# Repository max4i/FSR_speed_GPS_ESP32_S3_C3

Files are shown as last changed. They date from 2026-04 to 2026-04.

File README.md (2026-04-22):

# FSR Speed Tracker v9.5

## Telemetria dla łodzi wyścigowych FSR

## Spis treści

1. [Opis ogólny](#opis-ogólny)
2. [Wersja ESP32-S3 (pełna)](#wersja-esp32-s3-pełna)
3. [Wersja ESP32-C3 (lekka)](#wersja-esp32-c3-lekka)
4. [Porównanie wersji](#porównanie-wersji)
5. [Budowa i podłączenia](#budowa-i-podłączenia)
6. [Instalacja oprogramowania](#instalacja-oprogramowania)
7. [Konfiguracja](#konfiguracja)
8. [Obsługa systemu](#obsługa-systemu)
9. [Funkcje zaawansowane](#funkcje-zaawansowane)
10. [Rozwiązywanie problemów](#rozwiązywanie-problemów)
11. [Dane techniczne](#dane-techniczne)

---
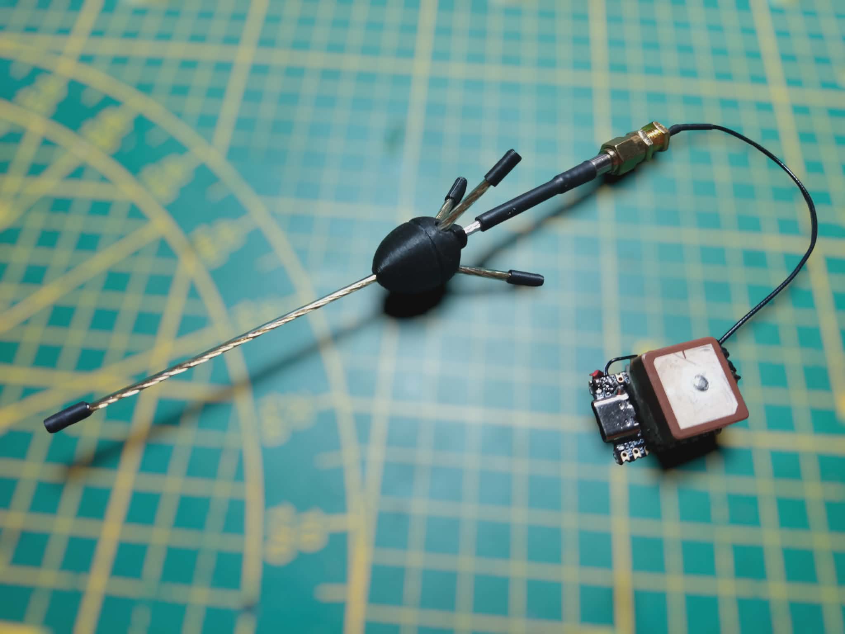
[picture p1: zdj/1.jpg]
[](zdj/1.jpg)
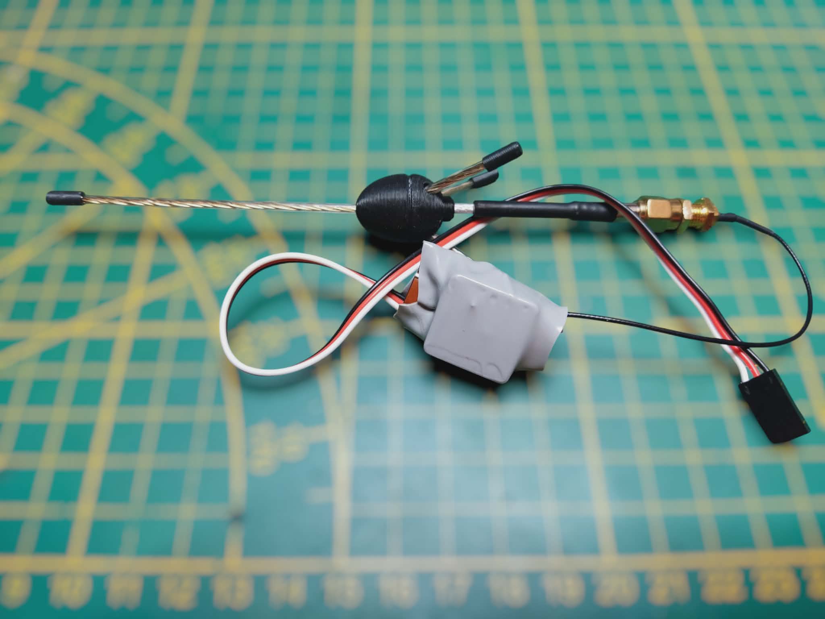
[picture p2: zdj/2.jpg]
[](zdj/2.jpg)
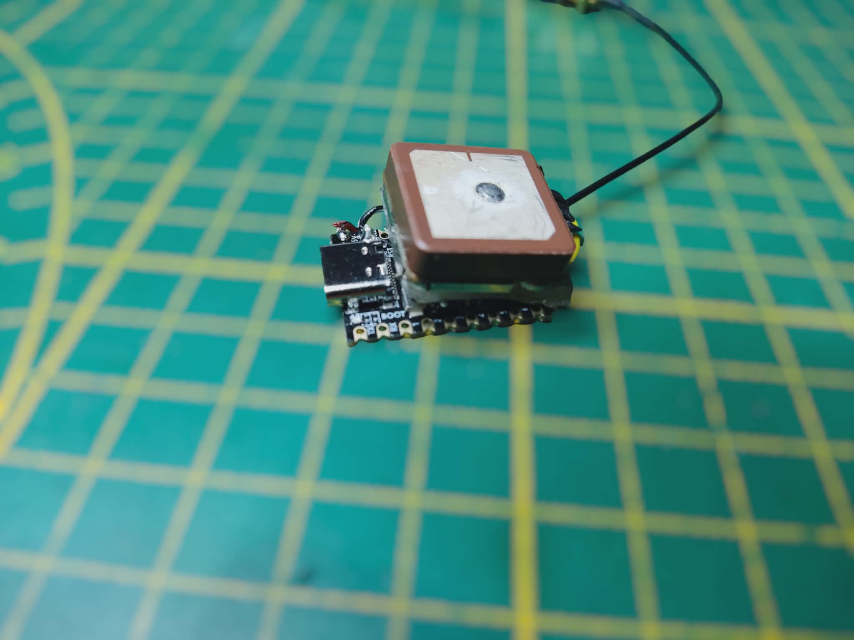
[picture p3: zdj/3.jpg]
[](zdj/3.jpg)

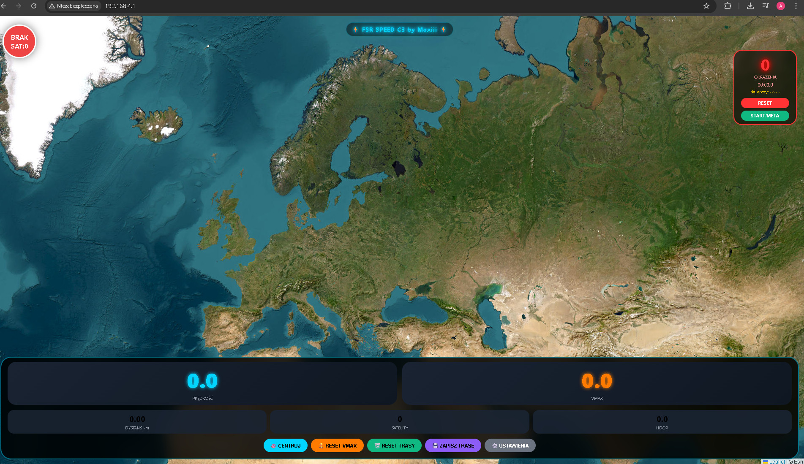
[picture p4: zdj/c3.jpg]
[](zdj/c3.jpg)
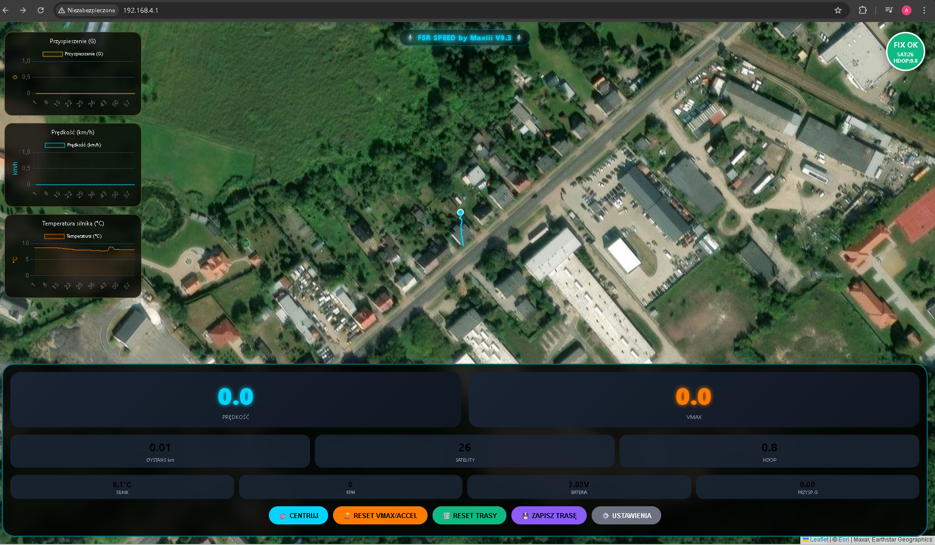
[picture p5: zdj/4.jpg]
[](zdj/4.jpg)

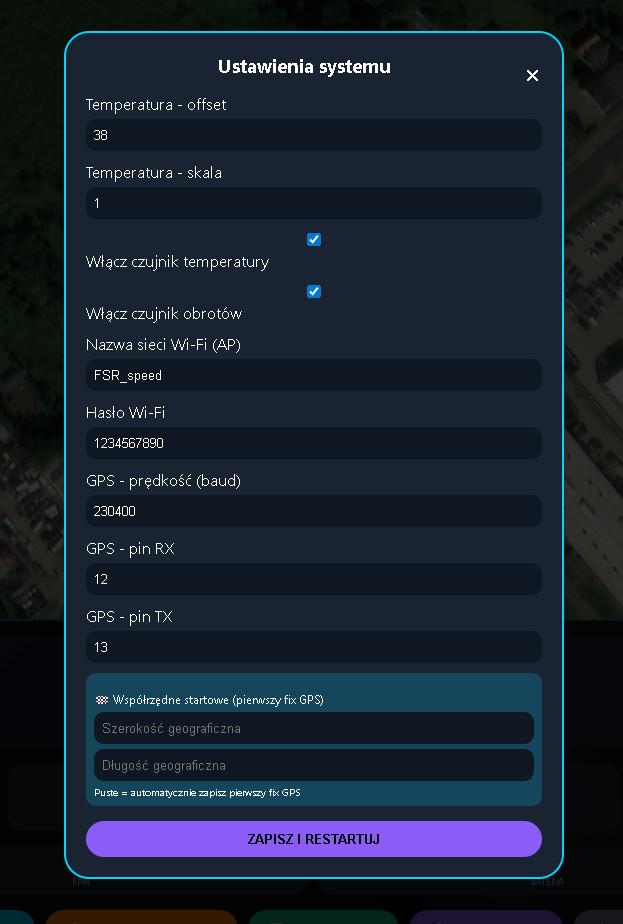
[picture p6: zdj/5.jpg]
[](zdj/5.jpg)

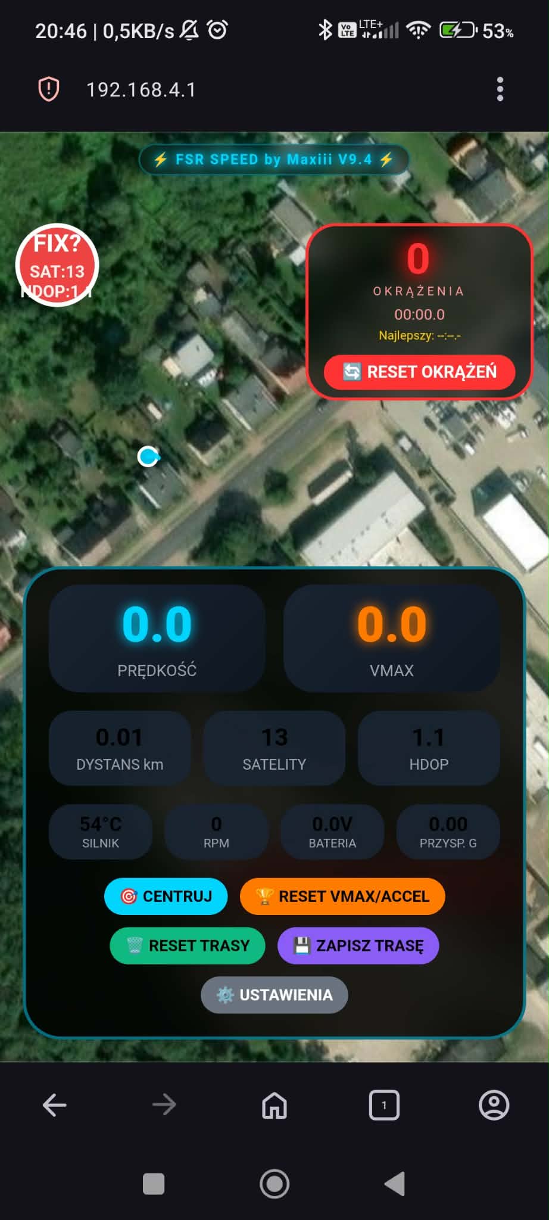
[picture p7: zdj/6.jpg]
[](zdj/6.jpg)
## Opis ogólny

System telemetrii dla łodzi wyścigowych **FSR** (Formuła Silnikowa Remote control) umożliwiający śledzenie parametrów pracy jednostki w czasie rzeczywistym. Urządzenie tworzy własną sieć Wi-Fi, do której można podłączyć telefon, tablet lub laptop, a następnie w przeglądarce internetowej obserwować:

- Pozycję łodzi na mapie satelitarnej
- Prędkość chwilową i maksymalną (VMAX)
- Przyspieszenie w jednostkach **G**
- Temperaturę silnika
- Obroty silnika (RPM)
- Napięcie baterii pokładowej
- Liczbę okrążeń z pomiarem czasu
- Przebyty dystans
- Trasę do zapisu w formacie **GPX**

System dostępny jest w dwóch wersjach sprzętowych.

---

## Wersja ESP32-S3 (pełna)

Pełna wersja oparta na **ESP32-S3 SuperMini** z PSRAM 2MB.

| Parametr | Wartość |
|---|---|
| Mikrokontroler | ESP32-S3 SuperMini (QFN56) |
| Pamięć Flash | 4 MB |
| Pamięć PSRAM | 2 MB (QSPI) |
| CPU | 240 MHz |
| Moduł GPS | HT1818Z3G5L z AT6558R (GPS+BDS, 10Hz) |
| Czujnik temp. | NTC 100kΩ (Beta=3950) |
| Czujnik obrotów | Hallotron 3144 |
| Pomiar napięcia | Dzielnik 2×100kΩ |
| Wi-Fi | 802.11b/g/n, kanał 1, moc 8.5–19.5 dBm |
| Zasięg Wi-Fi | do 300 m |
| Zasilanie | 5V lub 7.4V LiPo |
| Pobór prądu | ~350 mA |

**Funkcje:** wszystko (wykresy, regulacja mocy, zapis 6000 punktów).

---

## Wersja ESP32-C3 (lekka)

Uproszczona wersja na **ESP32-C3 SuperMini** (RISC-V).

| Parametr | Wartość |
|---|---|
| Mikrokontroler | ESP32-C3 SuperMini |
| Pamięć Flash | 4 MB |
| Pamięć RAM | 400 KB |
| CPU | 160 MHz |
| Moduł GPS | HT1818Z3G5L (10Hz) |
| Czujnik temp. | NTC 100kΩ (opcjonalnie) |
| Czujnik obrotów | brak (opcjonalnie) |
| Pomiar napięcia | brak |
| Wi-Fi | 802.11b/g/n, moc stała |
| Zasięg Wi-Fi | do 150 m |
| Zasilanie | 5V |
| Pobór prądu | ~200 mA |

**Funkcje:** podstawowe (prędkość, trasa, okrążenia, GPX). Brak wykresów i regulacji mocy.

---

## Porównanie wersji

| Cecha | ESP32-S3 | ESP32-C3 |
|---|---|---|
| Cena zestawu | ~93 zł | ~50 zł |
| Pobór prądu | 350 mA | 200 mA |
| Zasięg Wi-Fi | do 300 m | do 150 m |
| Bufor trasy | 6000 pkt | 1000 pkt |
| Pamięć PSRAM | 2 MB | brak |
| Wykresy w UI | tak | nie |
| Regulacja mocy Wi-Fi | tak | nie |
| Pomiar temperatury | tak | opcjonalnie |
| Pomiar obrotów | tak | nie |
| Pomiar baterii | tak | nie |
| Czas zapisu trasy | ~60 min | ~10 min |

---

## Budowa i podłączenia

### Wspólne elementy

| Element | Model |
|---|---|
| ESP | ESP32-S3 lub ESP32-C3 SuperMini |
| GPS | HT1818Z3G5L z AT6558R |
| Antena GPS | GP 5/8 |
| Kondensator | 1000µF/6.3V |

### Podłączenia dla ESP32-S3

| Element | GPIO |
|---|---|
| GPS TX → ESP RX | 12 |
| GPS RX ← ESP TX | 13 |
| Termistor NTC | 11 |
| Hallotron 3144 | 10 |
| Dzielnik baterii | 8 |

### Podłączenia dla ESP32-C3

| Element | GPIO |
|---|---|
| GPS TX → ESP RX | 5 |
| GPS RX ← ESP TX | 6 |
| Termistor NTC | 2 (opcjonalnie) |
| Hallotron | 3 (opcjonalnie) |

### Schemat (ESP32-S3)
ESP32-S3 SuperMini
┌─────────────────┐
│ │
GPS TX ──────►│ GPIO12 (UART RX)│
GPS RX ◄──────│ GPIO13 (UART TX)│
│ │
3.3V ──[100kΩ]─┼─┬─[NTC]───┐ │
│ │ │ │
│ └─► GPIO11│ │
│ │ │
Hallotron ──────┼─► GPIO10 │ │
│ │ │
Bateria(+) ─[100kΩ]─┬─[100kΩ]─┐│
│ │ ││
│ └─► GPIO8││
│ ││
Bateria(-) ─────┴──────────┴┘
│
[1000µF/6.3V]
│
GND

---

## Instalacja oprogramowania

### Wymagania

- Arduino IDE 2.0+
- Zainstalowane wsparcie dla ESP32 (Board Manager)

### Instalacja ESP32 w Arduino IDE

1. **Plik → Preferencje** → dodaj URL:

2. 2. **Narzędzia → Płyta → Menadżer płyt** → zainstaluj `ESP32`

### Ustawienia dla ESP32-S3

| Ustawienie | Wartość |
|---|---|
| Board | ESP32S3 Dev Module |
| USB Mode | CDC (Native USB) |
| USB CDC On Boot | Enabled |
| CPU Frequency | 80 MHz |
| Flash Mode | DIO |
| Flash Size | 4MB (32Mb) |
| Partition Scheme | Default 4MB with spiffs |
| PSRAM | OPI PSRAM |
| Upload Speed | 921600 |

### Ustawienia dla ESP32-C3

| Ustawienie | Wartość |
|---|---|
| Board | ESP32C3 Dev Module |
| CPU Frequency | 160 MHz |
| Flash Mode | DIO |
| Flash Size | 4MB (32Mb) |
| Partition Scheme | Default 4MB with spiffs |
| Upload Speed | 921600 |

### Wgrywanie programu

1. Pobierz pliki: `fsr_speed_v95_ino.ino` i `html.h`
2. Umieść je w jednym katalogu
3. Otwórz `.ino` w Arduino IDE
4. Wybierz płytę i port COM
5. Kliknij **Wgraj**

---

## Konfiguracja

### Pierwsze uruchomienie

1. ESP32 utworzy sieć Wi-Fi `FSR_speed`
2. Połącz się hasłem `1234567890`
3. W przeglądarce wejdź na `http://192.168.4.1`
4. Poczekaj na FIX GPS (zielone kółko)

### Ustawienia w interfejsie

| Kategoria | Parametr | Domyślnie |
|---|---|---|
| Temperatura | Offset | 38.0 |
| Temperatura | Skala | 1.0 |
| Wi-Fi | Moc nadajnika (S3) | 8.5 dBm |
| Wi-Fi | Tryb (S3) | n |
| Wi-Fi | SSID | FSR_speed |
| Wi-Fi | Hasło | 1234567890 |
| GPS | Baud | 230400 |
| GPS | Pin RX | 12 (S3) / 5 (C3) |
| GPS | Pin TX | 13 (S3) / 6 (C3) |

---

## Obsługa systemu

### Przyciski

| Przycisk | Funkcja |
|---|---|
| 🎯 CENTRUJ | Centruje mapę na łodzi |
| 🏆 RESET VMAX/ACCEL | Zeruje rekordy |
| 🗑️ RESET TRASY | Czyści trasę |
| 💾 ZAPISZ TRASĘ | Pobiera GPX |
| 🏁 USTAW LINIĘ START/META | Ustawia punkt start/meta |
| ⚙️ USTAWIENIA | Panel konfiguracji |

### Okrążenia

1. Ustaw punkt start/meta (przycisk na mapie)
2. System wykrywa wejście w promień 15 m
3. Liczy okrążenia i mierzy czasy
4. Zapamiętuje najlepszy czas

### Wizualizacja na mapie

| Element | Kolor |
|---|---|
| Aktualna pozycja | Niebieskie kółko |
| Trasa | Niebieska linia |
| VMAX | Pomarańczowa dymka |
| Max Accel | Złota dymka |
| Start/Meta | Czerwone kółko |

---

## Funkcje zaawansowane

### Wzory obliczeniowe

**Prędkość** – z NMEA RMC, filtr antydryf 3 km/h.

**Przyspieszenie**  
`a = (V_current - V_last) / dt`  
`G = a / 9.80665`

**Temperatura (NTC 100kΩ, Beta=3950)**  
`R = (100000 * V_adc) / (3.3 - V_adc)`  
`1/T = A + B*ln(R) + C*(ln(R))³`  
Stałe: A=0.001129148, B=0.000234125, C=0.0000000876741

**Obroty (RPM)**  
`RPM = (impulsy * 60000) / dt`

**Dystans** – wzór haversine, promień Ziemi 6371 km.

### Filtry

| Filtr | Wartość |
|---|---|
| Antydryf | 3 km/h |
| Mediana pozycji | 5 próbek |
| HDOP | < 2.0 |
| SAT | ≥ 4 |
| Dystans punktów | ≥ 0.5 m |

### Komendy GPS

| Komenda | Opis |
|---|---|
| `$PMTK220,100*2F` | 10 Hz |
| `$PMTK314,0,1,0,1,...*28` | Tylko GGA i RMC |
| `$PMTK251,230400*...` | Zmiana baudrate |
| `$PMTK286,1*23` | Zapis do pamięci |

---

## Rozwiązywanie problemów

### Brak sieci Wi-Fi

- Sprawdź wybór płyty (ESP32S3 Dev Module)
- Naciśnij RESET po wgraniu
- Zmniejsz moc w ustawieniach (8.5 dBm)

### GPS nie ma FIX

- Zapewnij widok na niebo
- Sprawdź piny (TX→GPIO12, RX→GPIO13)
- Poczekaj 1-2 minuty

### Temperatura 0°C

- Włącz czujnik w ustawieniach
- Sprawdź połączenie termistora

### Brak RPM

- Włącz czujnik
- Ustaw magnes 2-5 mm od Hallotrona
- Sprawdź polaryzację (biegun N)

### Mały zasięg Wi-Fi (S3)

- Zwiększ moc do 19.5 dBm
- Ustaw tryb 802.11b
- Użyj anteny GP 5/8

---

## Dane techniczne

### ESP32-S3

| Parametr | Wartość |
|---|---|
| Procesor | Xtensa LX7 dual-core |
| Częstotliwość | 240 MHz |
| Flash | 4 MB |
| PSRAM | 2 MB |
| Wi-Fi | 802.11 b/g/n |
| GPIO | 18 |

### ESP32-C3

| Parametr | Wartość |
|---|---|
| Procesor | RISC-V single-core |
| Częstotliwość | 160 MHz |
| Flash | 4 MB |
| RAM | 400 KB |
| Wi-Fi | 802.11 b/g/n |
| GPIO | 14 |

### GPS HT1818Z3G5L

| Parametr | Wartość |
|---|---|
| Chip | AT6558R |
| Systemy | GPS + BDS |
| Częstotliwość | 10 Hz |
| Czułość | -165 dBm |
| Dokładność | 2.5 m |

### NTC 100kΩ

| Temp. | Rezystancja |
|---|---|
| 0°C | ~327 kΩ |
| 25°C | 100 kΩ |
| 50°C | ~36 kΩ |
| 100°C | ~6.8 kΩ |
| 150°C | ~2.2 kΩ |

---

## Wersje oprogramowania

| Wersja | Data | Zmiany |
|---|---|---|
| v9.0 | 2025-01 | Podstawowa |
| v9.1 | 2025-02 | Autodetekcja GPS, 10Hz |
| v9.2 | 2025-03 | Wykresy po lewej, tryb mobilny |
| v9.3 | 2025-04 | Dymki VMAX/ACCEL |
| v9.4 | 2026-04 | Okrążenia, regulacja mocy Wi-Fi |
| v9.5 | 2026-04 | Wsparcie dla ESP32-C3 |

---
# FSR Speed ACC v0.9 – pomiar prędkości z dużą dokładnością przy wykorzystaniu ADXL345

System pomiaru prędkości, trasy i okrążeń dla łodzi FSR (Formuła Silnikowa RC).  
Łączy moduł GPS (AT6558R, 10Hz) z akcelerometrem ADXL345 (I2C) na platformie **ESP32-S3**.  
Dane są wyświetlane w czasie rzeczywistym na mapie satelitarnej przez przeglądarkę (Wi-Fi AP lub STA).  

---

## 🔧 Zastosowane filtry

| Filtr | Opis |
|---|---|
| **Antydryf** | Odrzuca prędkości < 5 km/h (eliminacja szumów postojowych) |
| **Mediana prędkości** | 3-próbkowa mediana surowego odczytu GPS (szybka reakcja) |
| **Filtr Hampela** | Wykrywa i odrzuca pojedyncze outlier’y („szpilki”) w akcelerometrze |
| **Savitzky–Golay** | Wygładzanie oknem 7 próbek, zachowujące szczyty prędkości |
| **Butterworth (LPF)** | Dolnoprzepustowy 20 Hz – odcina drgania silnika (>50 Hz) |
| **Adaptacyjna fuzja GPS/ACC** | Dynamiczne ważenie sygnałów w zależności od HDOP i przyspieszenia |
| **Filtr Kalmana** | Optymalna estymacja prędkości z modelu szumów |
| **Mediana końcowa** | 10-próbkowa mediana przed wyświetleniem |

---

## 📡 Podłączenie (ESP32-S3 SuperMini)

| Komponent | GPIO |
|---|---|
| GPS TX → ESP RX | 12 |
| GPS RX ← ESP TX | 13 |
| ADXL345 SCL | 8 |
| ADXL345 SDA | 9 |
| Termistor NTC | 11 (przez 100kΩ do 3.3V) |
| Dzielnik baterii (2×100kΩ) | 10 |

> **Uwaga:** Piny 19 i 20 są zajęte przez native USB ESP32-S3.

---

## 📐 Sposób liczenia danych

### Prędkość
- Odczyt NMEA RMC (`gps.speed.kmph()`)
- Filtr antydryf i mediana 3 próbek
- Fuzja z akcelerometrem:  
  `v_fused = 0.7·v_gps + 0.3·(v_fused + ∫a·dt)`

### Przyspieszenie
- Akcelerometr ADXL345 (zakres ±16G)
- Kalibracja offsetów (przycisk w UI)
- Filtr Butterworth 20 Hz + Hampel

### VMAX (prędkość maksymalna)
- Rejestrowana tylko gdy **HDOP < 1.4** i **SAT ≥ 6**
- Zapisywana do historii (max 10 wartości, wyświetlane 4 ostatnie unikalne)

### Okrążenia
- Ustawienie linii start/meta przez przycisk na mapie
- Promień wykrywania: 15 m
- Mierzony czas okrążenia i najlepszy czas

### Dystans
- Wzór haversine (promień Ziemi 6371 km)
- Minimalna odległość między punktami trasy: 0.5 m

### Dokładność prędkości (wyświetlana jako `Dok: ±x.xxx km/h`)
Dokładność = 0.36 × K_sat × K_hdop × (1/√3)

text
- `0.36 km/h` – bazowa dokładność GPS AT6558R (0.1 m/s)
- `K_sat = 1 - (SAT-4)/30` (ograniczony do 0.3–1.0)
- `K_hdop = HDOP / 1.0` (ograniczony do 0.5–2.0)

Przykładowo: **SAT=20, HDOP=0.7** → dokładność ±0.068 km/h.

---

## 📊 Osiągane dokładności

| Warunki | SAT | HDOP | Dokładność statyczna | Błąd dystansu (40 km) |
|---|-----|---|---|---|
| Optymalne (otwarta woda) | ≥20 | 0.3–0.6 | ±0.03–0.07 km/h | ±12–28 m |
| Dobre (małe fale) | 10–19 | 0.6–1.0 | ±0.07–0.15 km/h | ±28–60 m |
| Przeciętne | 6–9 | 1.0–1.4 | ±0.15–0.24 km/h | ±60–96 m |

> VMAX zapisywany tylko przy **SAT ≥ 6** i **HDOP < 1.4**.

---

## 🌐 Dostęp przez przeglądarkę

- **Tryb AP** (domyślnie): SSID `FSR_ACC`, hasło `12345678` → IP `192.168.4.1`
- **Tryb STA** (jeśli skonfigurowano): ESP32 łączy się z istniejącą siecią Wi-Fi
- **Nazwa lokalna:** `http://fsr.local` (mDNS)

---

## 📁 Struktura projektu
/
├── fsr_speed_acc.ino # kod główny
├── html_acc.h # strona główna (mapa, dane)
├── info.h # strona informacyjna
└── config.json # automatycznie tworzony plik konfiguracji

text

---

## ⚙️ Konfiguracja w Arduino IDE (ESP32-S3)

| Ustawienie | Wartość |
|---|---|
| Board | ESP32S3 Dev Module |
| USB Mode | CDC (Native USB) |
| CPU Frequency | 240 MHz |
| Flash Mode | QIO |
| Flash Size | 4MB (32Mb) |
| Partition Scheme | No OTA (2MB APP/2MB SPIFFS) |
| PSRAM | QSPI PSRAM |

---

## 🚤 Przykład użycia

1. Wgraj kod do ESP32-S3.
2. Połącz się z siecią `FSR_ACC` (hasło `12345678`).
3. Otwórz `http://fsr.local` lub `http://192.168.4.1`.
4. Zaczekaj na fix GPS (zielony wskaźnik).
5. Rozpocznij jazdę – na mapie pojawi się trasa, prędkość i okrążenia.
6. Aby ustawić linię start/meta – kliknij przycisk **🏁 USTAW START** w pozycji gdzie chcesz rozpocząć pomiar okrążeń.

---

## Licencja

Projekt open-source.

## Autorzy

**Maxiii** i **Deepseek**

---

**FSR Speed Tracker v9.5 – Profesjonalna telemetria dla Twojej łodzi wyścigowej** 🚤

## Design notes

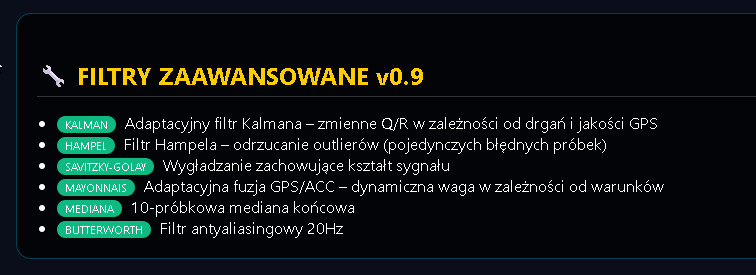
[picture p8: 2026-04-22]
aduino/s3+adxl345/Snap5.jpg

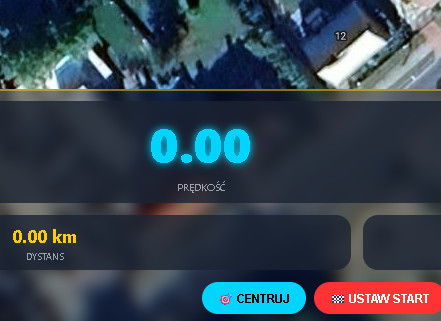
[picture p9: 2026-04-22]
aduino/s3+adxl345/Snap7.jpg

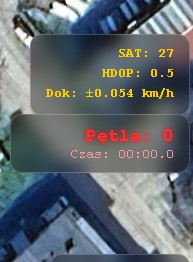
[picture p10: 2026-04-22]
aduino/s3+adxl345/Snap8.jpg

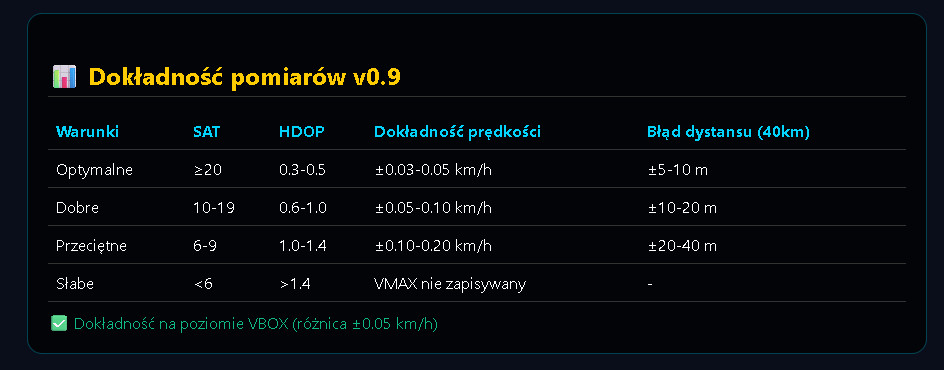
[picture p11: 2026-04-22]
aduino/s3+adxl345/Snap6.jpg

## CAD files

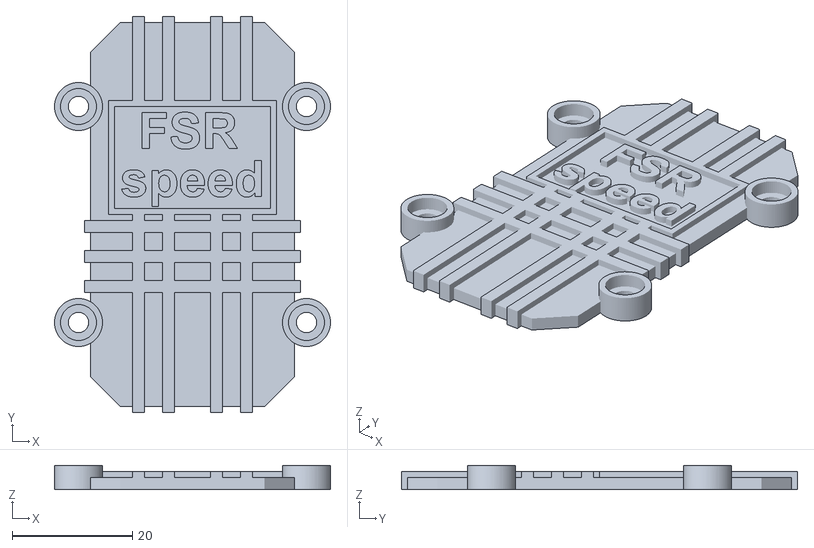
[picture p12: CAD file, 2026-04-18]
stl/g.stl
46.0 x 66.0 x 4.00

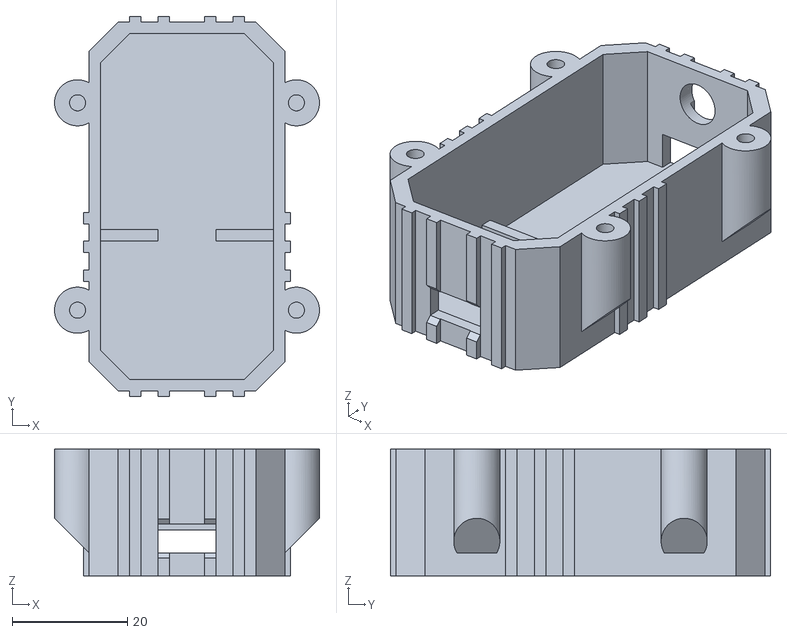
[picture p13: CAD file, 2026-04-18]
stl/d.stl
46.0 x 66.0 x 22.0

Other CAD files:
stl/fsr_obudowa.3dm

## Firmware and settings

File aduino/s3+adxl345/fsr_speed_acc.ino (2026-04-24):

/*
 * ============================================================================
 * FSR SPEED ACC v0.9 - GPS + ADXL345
 * ============================================================================
 * 
 * DATA:        2026-04-23
 * AUTORZY:     Maxiii & Deepseek
 * 
 * NOWOŚCI W v0.9:
 * - Asynchroniczny serwer (AsyncWebServer) – stabilność Wi-Fi
 * - Kalibracja ADXL345 (endpoint /api/calibrate)
 * - Prędkość i VMAX z dwoma miejscami po przecinku
 * - ODTWARZANIE TRASY PO ODŚWIEŻENIU STRONY (/api/track)
 * - Eksport VMAX do CSV (/api/vmaxcsv)
 * - Zapamiętywanie numeru i CZASU najlepszego okrążenia
 * - Nagłówki cache dla buforowania strony (1 rok)
 * - Google Satellite mapa z wysoką rozdzielczością
 * 
 * ============================================================================
 */

#include <WiFi.h>
#include <SPIFFS.h>
#include <HardwareSerial.h>
#include <TinyGPSPlus.h>
#include <ArduinoJson.h>
#include <esp_wifi.h>
#include <Wire.h>
#include <Adafruit_Sensor.h>
#include <Adafruit_ADXL345_U.h>
#include <ESPmDNS.h>
#include <AsyncTCP.h>
#include <ESPAsyncWebServer.h>

// ==================== PINY ====================
#define GPS_RX_PIN 12
#define GPS_TX_PIN 13
#define GPS_BAUD 230400
#define TEMP_SENSOR_PIN 11
#define BATT_SENSOR_PIN 10
#define I2C_SDA 9
#define I2C_SCL 8

// ==================== PARAMETRY ====================
#define HDOP_GOOD_THRESHOLD 1.4
#define MIN_SATELLITES 6
#define SPEED_THRESHOLD 5.0
#define DISTANCE_MIN 0.5
#define MAX_TRACK_POINTS 6000
#define TEMP_FILTER_WINDOW 10
#define SPEED_FILTER_WINDOW 3
#define ACCEL_FILTER_WINDOW 5
#define VMAX_MIN_SPEED 5.0
#define MS2_TO_G 0.101971621
#define WIFI_TIMEOUT 10000

// ==================== SERWER ASYNCHRONICZNY ====================
AsyncWebServer server(80);

// ==================== STRUKTURY ====================
struct Config {
  float temp_offset = 38.0;
  float temp_scale = 1.0;
  bool temp_enabled = true;
  char wifi_ssid[32] = "FSR_ACC";
  char wifi_password[32] = "12345678";
  char sta_ssid[32] = "";
  char sta_password[32] = "";
  uint32_t gps_baud = GPS_BAUD;
  int gps_rx_pin = GPS_RX_PIN;
  int gps_tx_pin = GPS_TX_PIN;
  float start_lat = 0.0;
  float start_lon = 0.0;
  bool start_set = false;
  float start_line_lat = 0.0;
  float start_line_lon = 0.0;
  float start_line_radius = 15.0;
  int laps = 0;
  float best_lap_time = 0;
  int best_lap_number = 0;
  unsigned long lap_start_time = 0;
  int wifi_power = 0;
  int wifi_mode = 2;
  int vmax_count = 0;
  float vmax_history[10] = {0};
  float vmax_lat[10] = {0};
  float vmax_lon[10] = {0};
  float accel_offset_x = 0.0;
  float accel_offset_y = 0.0;
  float accel_offset_z = 0.0;
  bool accel_calibrated = false;
};

struct TrackPoint {
    float lat;
    float lon;
    float speed;
    float temp;
    unsigned long timestamp;
};

// ==================== GLOBALNE ====================
Config config;
IPAddress local_ip(192, 168, 4, 1);
IPAddress gateway(192, 168, 4, 1);
IPAddress subnet(255, 255, 255, 0);
TinyGPSPlus gps;
HardwareSerial GPS_Serial(1);
Adafruit_ADXL345_Unified adxl = Adafruit_ADXL345_Unified(12345);

// Zmienne
float currentSpeed = 0;
float maxSpeed = 0;
float maxSpeedLat = 0;
float maxSpeedLon = 0;
float totalDistance = 0;
float lastLat = 0;
float lastLon = 0;
float lastSpeed = 0;
unsigned long lastSpeedTime = 0;
bool firstFix = true;
bool startPositionRecorded = false;
bool wifiStarted = false;
bool wifiConnected = false;
bool lastInsideStartLine = false;

// Filtry
float speedHistory[SPEED_FILTER_WINDOW];
int speedIndex = 0;
bool speedReady = false;
float fusedSpeed = 0;

// Bufor pozycji
float latBuffer[5];
float lonBuffer[5];
int bufferIndex = 0;
bool bufferFull = false;

// Temperatura
float tempEngine = 0.0f;
float tempBuffer[TEMP_FILTER_WINDOW];
int tempIndex = 0;

// Bateria
float batteryVoltage = 0.0f;

// Trasa
TrackPoint* trackBuffer = nullptr;
int trackCount = 0;
unsigned long lastDataTime = 0;

#include "html_acc.h"
#include "info.h"

// ==================== FUNKCJE POMOCNICZE ====================
float medianFilter(float *data, int size) {
  float sorted[size];
  memcpy(sorted, data, sizeof(float) * size);
  for (int i = 0; i < size - 1; i++) {
    for (int j = 0; j < size - i - 1; j++) {
      if (sorted[j] > sorted[j + 1]) {
        float t = sorted[j];
        sorted[j] = sorted[j + 1];
        sorted[j + 1] = t;
      }
    }
  }
  return sorted[size / 2];
}

float getFilteredSpeed(float rawSpeed) {
  if (isnan(rawSpeed) || isinf(rawSpeed)) return 0;
  if (rawSpeed < SPEED_THRESHOLD) return 0;
  speedHistory[speedIndex % SPEED_FILTER_WINDOW] = rawSpeed;
  speedIndex++;
  if (speedIndex >= SPEED_FILTER_WINDOW) speedReady = true;
  if (speedReady) return medianFilter(speedHistory, SPEED_FILTER_WINDOW);
  return rawSpeed;
}

float fuseSpeed(float gpsSpeed, float accelX, float dt) {
  if (dt == 0 || dt > 500) return gpsSpeed;
  float accelMs2 = accelX * 9.80665;
  float deltaV = accelMs2 * (dt / 1000.0);
  float fused = 0.7 * gpsSpeed + 0.3 * (fusedSpeed + deltaV);
  if (fused < 0) fused = 0;
  if (fused > 200) fused = 200;
  return fused;
}

float calculateSpeedAccuracy(int satellites, float hdop) {
  float baseError = 0.36;
  float satFactor = 1.0 - ((satellites - 4) / 30.0);
  if (satFactor < 0.3) satFactor = 0.3;
  if (satFactor > 1.0) satFactor = 1.0;
  float hdopFactor = hdop / 1.0;
  if (hdopFactor < 0.5) hdopFactor = 0.5;
  float result = baseError * satFactor * hdopFactor;
  if (result < 0.05) result = 0.05;
  if (result > 1.0) result = 1.0;
  return result;
}

void addVMAXToHistory(float speed, float lat, float lon) {
  if (config.vmax_count < 10) {
    config.vmax_history[config.vmax_count] = speed;
    config.vmax_lat[config.vmax_count] = lat;
    config.vmax_lon[config.vmax_count] = lon;
    config.vmax_count++;
  } else {
    for (int i = 0; i < 9; i++) {
      config.vmax_history[i] = config.vmax_history[i + 1];
      config.vmax_lat[i] = config.vmax_lat[i + 1];
      config.vmax_lon[i] = config.vmax_lon[i + 1];
    }
    config.vmax_history[9] = speed;
    config.vmax_lat[9] = lat;
    config.vmax_lon[9] = lon;
  }
  saveConfig();
}

// ==================== KONFIGURACJA ====================
void loadConfig() {
  File file = SPIFFS.open("/config.json", "r");
  if (!file) {
    saveConfig();
    return;
  }
  StaticJsonDocument<2048> doc;
  DeserializationError error = deserializeJson(doc, file);
  file.close();
  if (error) return;
  
  config.temp_offset = doc["temp_offset"] | 38.0;
  config.temp_scale = doc["temp_scale"] | 1.0;
  config.temp_enabled = doc["temp_enabled"] | true;
  strlcpy(config.wifi_ssid, doc["wifi_ssid"] | "FSR_ACC", sizeof(config.wifi_ssid));
  strlcpy(config.wifi_password, doc["wifi_password"] | "12345678", sizeof(config.wifi_password));
  strlcpy(config.sta_ssid, doc["sta_ssid"] | "", sizeof(config.sta_ssid));
  strlcpy(config.sta_password, doc["sta_password"] | "", sizeof(config.sta_password));
  config.gps_baud = doc["gps_baud"] | GPS_BAUD;
  config.gps_rx_pin = doc["gps_rx_pin"] | GPS_RX_PIN;
  config.gps_tx_pin = doc["gps_tx_pin"] | GPS_TX_PIN;
  config.start_lat = doc["start_lat"] | 0.0;
  config.start_lon = doc["start_lon"] | 0.0;
  config.start_set = doc["start_set"] | false;
  config.start_line_lat = doc["start_line_lat"] | 0.0;
  config.start_line_lon = doc["start_line_lon"] | 0.0;
  config.start_line_radius = doc["start_line_radius"] | 15.0;
  config.laps = doc["laps"] | 0;
  config.best_lap_time = doc["best_lap_time"] | 0;
  config.best_lap_number = doc["best_lap_number"] | 0;
  config.lap_start_time = doc["lap_start_time"] | 0;
  config.wifi_power = doc["wifi_power"] | 0;
  config.wifi_mode = doc["wifi_mode"] | 2;
  config.vmax_count = doc["vmax_count"] | 0;
  for (int i = 0; i < 10; i++) {
    config.vmax_history[i] = doc["vmax_" + String(i)] | 0;
    config.vmax_lat[i] = doc["vmax_lat_" + String(i)] | 0;
    config.vmax_lon[i] = doc["vmax_lon_" + String(i)] | 0;
  }
  config.accel_offset_x = doc["accel_offset_x"] | 0.0;
  config.accel_offset_y = doc["accel_offset_y"] | 0.0;
  config.accel_offset_z = doc["accel_offset_z"] | 0.0;
  config.accel_calibrated = doc["accel_calibrated"] | false;
}

void saveConfig() {
  StaticJsonDocument<2048> doc;
  doc["temp_offset"] = config.temp_offset;
  doc["temp_scale"] = config.temp_scale;
  doc["temp_enabled"] = config.temp_enabled;
  doc["wifi_ssid"] = config.wifi_ssid;
  doc["wifi_password"] = config.wifi_password;
  doc["sta_ssid"] = config.sta_ssid;
  doc["sta_password"] = config.sta_password;
  doc["gps_baud"] = config.gps_baud;
  doc["gps_rx_pin"] = config.gps_rx_pin;
  doc["gps_tx_pin"] = config.gps_tx_pin;
  doc["start_lat"] = config.start_lat;
  doc["start_lon"] = config.start_lon;
  doc["start_set"] = config.start_set;
  doc["start_line_lat"] = config.start_line_lat;
  doc["start_line_lon"] = config.start_line_lon;
  doc["start_line_radius"] = config.start_line_radius;
  doc["laps"] = config.laps;
  doc["best_lap_time"] = config.best_lap_time;
  doc["best_lap_number"] = config.best_lap_number;
  doc["lap_start_time"] = config.lap_start_time;
  doc["wifi_power"] = config.wifi_power;
  doc["wifi_mode"] = config.wifi_mode;
  doc["vmax_count"] = config.vmax_count;
  for (int i = 0; i < 10; i++) {
    doc["vmax_" + String(i)] = config.vmax_history[i];
    doc["vmax_lat_" + String(i)] = config.vmax_lat[i];
    doc["vmax_lon_" + String(i)] = config.vmax_lon[i];
  }
  doc["accel_offset_x"] = config.accel_offset_x;
  doc["accel_offset_y"] = config.accel_offset_y;
  doc["accel_offset_z"] = config.accel_offset_z;
  doc["accel_calibrated"] = config.accel_calibrated;
  
  File file = SPIFFS.open("/config.json", "w");
  if (file) {
    serializeJson(doc, file);
    file.close();
  }
}

String scanNetworks() {
  String json = "[";
  int n = WiFi.scanComplete();
  if (n == -2) {
    WiFi.scanNetworks(true);
    return "{\"status\":\"scanning\"}";
  } else if (n > 0) {
    for (int i = 0; i < n; ++i) {
      if (i > 0) json += ",";
      json += "\"" + WiFi.SSID(i) + "\"";
    }
    WiFi.scanDelete();
  }
  json += "]";
  return json;
}

void startWiFiHybrid() {
  Serial.println("[WiFi] Tryb hybrydowy: najpierw próba połączenia...");
  
  if (strlen(config.sta_ssid) > 0) {
    WiFi.mode(WIFI_STA);
    WiFi.begin(config.sta_ssid, config.sta_password);
    
    unsigned long start = millis();
    while (millis() - start < WIFI_TIMEOUT) {
      if (WiFi.status() == WL_CONNECTED) {
        wifiConnected = true;
        Serial.printf("[WiFi] Połączono z %s, IP: %s\n", config.sta_ssid, WiFi.localIP().toString().c_str());
        break;
      }
      delay(500);
      Serial.print(".");
    }
  }
  
  if (!wifiConnected) {
    Serial.println("\n[WiFi] Brak połączenia, uruchamiam Access Point...");
    WiFi.mode(WIFI_AP);
    WiFi.softAPConfig(local_ip, gateway, subnet);
    
    wifi_power_t powerLevel;
    switch(config.wifi_power) {
      case 0: powerLevel = WIFI_POWER_8_5dBm; break;
      case 1: powerLevel = WIFI_POWER_11dBm; break;
      case 2: powerLevel = WIFI_POWER_13dBm; break;
      case 3: powerLevel = WIFI_POWER_17dBm; break;
      default: powerLevel = WIFI_POWER_19_5dBm; break;
    }
    WiFi.setTxPower(powerLevel);
    
    if (config.wifi_mode == 0) esp_wifi_set_protocol(WIFI_IF_AP, WIFI_PROTOCOL_11B);
    else if (config.wifi_mode == 1) esp_wifi_set_protocol(WIFI_IF_AP, WIFI_PROTOCOL_11G);
    else esp_wifi_set_protocol(WIFI_IF_AP, WIFI_PROTOCOL_11N);
    
    if (WiFi.softAP(config.wifi_ssid, config.wifi_password, 1, 0, 4)) {
      wifiStarted = true;
      Serial.printf("[WiFi] AP '%s' uruchomiony, IP: %s\n", config.wifi_ssid, WiFi.softAPIP().toString().c_str());
      WiFi.setSleep(false);
      Serial.println("[WiFi] Tryb uśpienia: WYŁĄCZONY");
    }
  } else {
    wifiStarted = true;
    WiFi.setSleep(false);
  }
  
  if (!MDNS.begin("fsr")) {
    Serial.println("[MDNS] Błąd uruchomienia mDNS");
  } else {
    Serial.println("[MDNS] Serwer nazw uruchomiony: http://fsr.local");
    MDNS.addService("http", "tcp", 80);
  }
}

// ==================== FUNKCJE GPS ====================
float calculateDistance(float lat1, float lon1, float lat2, float lon2) {
  float R = 6371;
  float dlat = (lat2 - lat1) * PI / 180;
  float dlon = (lon2 - lon1) * PI / 180;
  float a = sin(dlat/2) * sin(dlat/2) + cos(lat1*PI/180) * cos(lat2*PI/180) * sin(dlon/2) * sin(dlon/2);
  float c = 2 * atan2(sqrt(a), sqrt(1-a));
  return R * c;
}

float calculateDistanceToPoint(float lat1, float lon1, float lat2, float lon2) {
  float R = 6371000;
  float dlat = (lat2 - lat1) * PI / 180;
  float dlon = (lon2 - lon1) * PI / 180;
  float a = sin(dlat/2) * sin(dlat/2) + cos(lat1*PI/180) * cos(lat2*PI/180) * sin(dlon/2) * sin(dlon/2);
  float c = 2 * atan2(sqrt(a), sqrt(1-a));
  return R * c;
}

void checkLap(float currentLat, float currentLon, unsigned long currentTime) {
  if (config.start_line_lat == 0 && config.start_line_lon == 0) return;
  
  float distance = calculateDistanceToPoint(currentLat, currentLon, config.start_line_lat, config.start_line_lon);
  bool inside = (distance < config.start_line_radius);
  
  if (inside && !lastInsideStartLine) {
    if (config.laps == 0) {
      config.lap_start_time = currentTime;
      Serial.println("[LAP] Start pomiaru okrążeń");
    } else {
      float lapTime = (currentTime - config.lap_start_time) / 1000.0;
      if (config.best_lap_time == 0 || lapTime < config.best_lap_time) {
        config.best_lap_time = lapTime;
        config.best_lap_number = config.laps + 1;
        Serial.printf("[LAP] NOWY REKORD! %.2f s (okrążenie %d)\n", lapTime, config.best_lap_number);
      }
      config.lap_start_time = currentTime;
      config.laps++;
      saveConfig();
      Serial.printf("[LAP] Okrążenie #%d: %.2f s\n", config.laps, lapTime);
    }
  }
  lastInsideStartLine = inside;
}

void addPositionToBuffer(float lat, float lon) {
  latBuffer[bufferIndex] = lat;
  lonBuffer[bufferIndex] = lon;
  bufferIndex++;
  if (bufferIndex >= 5) { bufferIndex = 0; bufferFull = true; }
}

float getMedianLat() {
  if (!bufferFull && bufferIndex < 2) return gps.location.lat();
  float temp[5];
  int count = bufferFull ? 5 : bufferIndex;
  for (int i = 0; i < count; i++) temp[i] = latBuffer[i];
  for (int i = 0; i < count-1; i++)
    for (int j = 0; j < count-i-1; j++)
      if (temp[j] > temp[j+1]) { float t = temp[j]; temp[j] = temp[j+1]; temp[j+1] = t; }
  return temp[count/2];
}

float getMedianLon() {
  if (!bufferFull && bufferIndex < 2) return gps.location.lng();
  float temp[5];
  int count = bufferFull ? 5 : bufferIndex;
  for (int i = 0; i < count; i++) temp[i] = lonBuffer[i];
  for (int i = 0; i < count-1; i++)
    for (int j = 0; j < count-i-1; j++)
      if (temp[j] > temp[j+1]) { float t = temp[j]; temp[j] = temp[j+1]; temp[j+1] = t; }
  return temp[count/2];
}

void addTrackPoint(float lat, float lon, float speed, float temp) {
  if (trackBuffer && trackCount < MAX_TRACK_POINTS) {
    trackBuffer[trackCount] = {lat, lon, speed, temp, millis()};
    trackCount++;
  }
}

void initPSRAM() {
  if (psramFound()) {
    trackBuffer = (TrackPoint*)ps_malloc(sizeof(TrackPoint) * MAX_TRACK_POINTS);
  } else {
    trackBuffer = (TrackPoint*)malloc(sizeof(TrackPoint) * MAX_TRACK_POINTS);
  }
}

float readTemperature() {
  if (!config.temp_enabled) return 0;
  int raw = analogRead(TEMP_SENSOR_PIN);
  if (raw <= 0 || raw >= 4095) return 21.0f;
  
  float voltage = (raw / 4095.0) * 3.3;
  float resistance = (100000.0 * voltage) / (3.3 - voltage);
  float logR = log(resistance);
  float temp = 1.0 / (0.001129148 + 0.000234125 * logR + 0.0000000876741 * logR * logR * logR);
  temp = temp - 273.15;
  temp = temp * config.temp_scale + config.temp_offset;
  
  tempBuffer[tempIndex % TEMP_FILTER_WINDOW] = temp;
  tempIndex++;
  if (tempIndex >= TEMP_FILTER_WINDOW) {
    float sum = 0;
    for (int i = 0; i < TEMP_FILTER_WINDOW; i++) sum += tempBuffer[i];
    return sum / TEMP_FILTER_WINDOW;
  }
  return temp;
}

float readBattery() {
  int raw = analogRead(BATT_SENSOR_PIN);
  if (raw <= 0 || raw >= 4095) return 0.0f;
  return (raw / 4095.0) * 3.3 * 2.0;
}

// ==================== OBSŁUGA ENDPOINTÓW ====================
void handleRoot(AsyncWebServerRequest *request) {
  AsyncWebServerResponse *response = request->beginResponse(200, "text/html", index_html);
  response->addHeader("Cache-Control", "public, max-age=31536000, immutable");
  request->send(response);
}

void handleInfo(AsyncWebServerRequest *request) {
  AsyncWebServerResponse *response = request->beginResponse(200, "text/html", info_html);
  response->addHeader("Cache-Control", "public, max-age=31536000, immutable");
  request->send(response);
}

void handleScanWiFi(AsyncWebServerRequest *request) {
  String json = scanNetworks();
  request->send(200, "application/json", json);
}

void handleCalibrate(AsyncWebServerRequest *request) {
  Serial.println("[CALIB] Rozpoczynam kalibrację ADXL345...");
  float sumX = 0, sumY = 0, sumZ = 0;
  const int samples = 100;
  for (int i = 0; i < samples; i++) {
    sensors_event_t event;
    adxl.getEvent(&event);
    sumX += event.acceleration.x;
    sumY += event.acceleration.y;
    sumZ += event.acceleration.z;
    delay(10);
  }
  config.accel_offset_x = sumX / samples;
  config.accel_offset_y = sumY / samples;
  config.accel_offset_z = sumZ / samples - 1.0;
  config.accel_calibrated = true;
  saveConfig();
  Serial.printf("[CALIB] Offsety: X=%.3f, Y=%.3f, Z=%.3f\n", 
                config.accel_offset_x, config.accel_offset_y, config.accel_offset_z);
  request->send(200, "text/plain", "Kalibracja zakończona");
}
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
void loop() {
  while (GPS_Serial.available()) {
    gps.encode(GPS_Serial.read());
  }
  
  sensors_event_t event;
  adxl.getEvent(&event);
  float accelX = event.acceleration.x;
  float accelY = event.acceleration.y;
  float accelZ = event.acceleration.z;
  if (config.accel_calibrated) {
    accelX -= config.accel_offset_x;
    accelY -= config.accel_offset_y;
    accelZ -= config.accel_offset_z;
  }
  
  if (gps.speed.isValid() && gps.location.isValid()) {
    float rawSpeed = gps.speed.kmph();
    float filteredSpeed = getFilteredSpeed(rawSpeed);
    unsigned long now = millis();
    unsigned long dt = now - lastSpeedTime;
    
    if (lastSpeedTime > 0 && dt > 0 && dt < 500) {
      fusedSpeed = fuseSpeed(filteredSpeed, accelX, dt);
    } else {
      fusedSpeed = filteredSpeed;
    }
    
    float hdop = gps.hdop.isValid() ? gps.hdop.hdop() : 99.9;
    int sat = gps.satellites.value();
    
    if (hdop < HDOP_GOOD_THRESHOLD && sat >= MIN_SATELLITES) {
      if (fusedSpeed > maxSpeed && fusedSpeed > VMAX_MIN_SPEED) {
        maxSpeed = fusedSpeed;
        maxSpeedLat = getMedianLat();
        maxSpeedLon = getMedianLon();
        addVMAXToHistory(maxSpeed, maxSpeedLat, maxSpeedLon);
        Serial.printf("[VMAX] Nowy rekord: %.2f km/h\n", maxSpeed);
      }
    }
    
    lastSpeed = fusedSpeed;
    lastSpeedTime = now;
    currentSpeed = fusedSpeed;
  }
  
  if (gps.location.isValid()) {
    float lat = gps.location.lat();
    float lon = gps.location.lng();
    addPositionToBuffer(lat, lon);
    
    float hdop = gps.hdop.isValid() ? gps.hdop.hdop() : 99.9;
    int sat = gps.satellites.value();
    
    checkLap(lat, lon, millis());
    
    if (!startPositionRecorded && !config.start_set && hdop < HDOP_GOOD_THRESHOLD && sat >= MIN_SATELLITES) {
      config.start_lat = lat;
      config.start_lon = lon;
      config.start_set = true;
      startPositionRecorded = true;
      saveConfig();
      Serial.printf("[START] Zapisano pozycję startową: %.6f, %.6f\n", lat, lon);
    }
    
    if (hdop < 2.0 && sat >= 4) {
      if (!firstFix) {
        float dist = calculateDistance(lastLat, lastLon, lat, lon);
        if (dist * 1000 > DISTANCE_MIN) totalDistance += dist;
      } else firstFix = false;
      lastLat = lat;
      lastLon = lon;
    }
  }
  
  static unsigned long lastTemp = 0;
  if (millis() - lastTemp >= 500) { lastTemp = millis(); tempEngine = readTemperature(); }
  
  static unsigned long lastBatt = 0;
  if (millis() - lastBatt >= 2000) { lastBatt = millis(); batteryVoltage = readBattery(); }
  
  if (millis() - lastDataTime >= 100) {
    lastDataTime = millis();
    if (gps.location.isValid()) {
      float hdop = gps.hdop.isValid() ? gps.hdop.hdop() : 99.9;
      int sat = gps.satellites.value();
      if (hdop < 2.0 && sat >= 4) {
        float lat = getMedianLat();
        float lon = getMedianLon();
        float dispSpeed = (currentSpeed < SPEED_THRESHOLD) ? 0 : currentSpeed;
        addTrackPoint(lat, lon, dispSpeed, tempEngine);
      }
    }
  }
  
  static unsigned long lastDebug = 0;
  if (millis() - lastDebug > 5000) {
    lastDebug = millis();
    if (gps.location.isValid()) {
      float hdop = gps.hdop.isValid() ? gps.hdop.hdop() : 99.9;
      int clients = WiFi.softAPgetStationNum();
      Serial.printf("📍 %.6f,%.6f | ⚡ %.2f km/h | VMAX:%.2f | SAT:%d | HDOP:%.1f | 🏁 %d | Klienci: %d\n",
        getMedianLat(), getMedianLon(), currentSpeed, maxSpeed, gps.satellites.value(), hdop, config.laps, clients);
    }
  }
  
  delay(1);
}

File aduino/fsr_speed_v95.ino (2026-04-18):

/*
 * ============================================================================
 * FSR SPEED TRACKER v9.4 - OPIS TECHNICZNY
 * ============================================================================
 * 
 * AUTOR:        Maxiii & Deepseek
 * WERSJA:       9.4 (final)
 * DATA:         2026-04-14
 * 
 * ============================================================================
 * OPIS OGÓLNY SYSTEMU
 * ============================================================================
 * 
 * System telemetrii dedykowany dla łodzi wyścigowych FSR (Formuła Silnikowa
 * Remote control). Urządzenie zbiera dane z GPS, czujnika temperatury silnika,
 * czujnika obrotów (RPM) oraz napięcia baterii. Dane są wyświetlane w czasie
 * rzeczywistym na mapie satelitarnej przez przeglądarkę internetową.
 * 
 * Główne funkcje:
 * - Śledzenie trasy na mapie satelitarnej Esri World Imagery (zoom 1-20)
 * - Wyświetlanie aktualnej prędkości, VMAX i maksymalnego przyspieszenia
 * - Trzy wykresy: prędkość (km/h), temperatura (°C), przyspieszenie (G)
 * - Automatyczne wykrywanie okrążeń z pomiarem czasów
 * - Zapisywanie trasy do pliku GPX z danymi: temp, RPM, przyspieszenie
 * - Regulacja mocy i trybu Wi-Fi (zasięg do 300m)
 * - Konfiguracja przez przeglądarkę internetową
 * - Tryb mobilny (automatyczne ukrywanie wykresów)
 * 
 * ============================================================================
 * BUDOWA SPRZĘTOWA
 * ============================================================================
 * 
 * GŁÓWNE ELEMENTY:
 * ----------------------------------------------------------------------------
 * | Element              | Model                      | Funkcja               |
 * |----------------------|----------------------------|-----------------------|
 * | Mikrokontroler       | ESP32-S3 SuperMini         | CPU, Wi-Fi AP, PSRAM  |
 * | Moduł GPS            | HT1818Z3G5L z AT6558R      | GPS+BDS Beidou, 10Hz  |
 * | Antena GPS           | GP 5/8 (złączka U.FL)      | Zwiększenie zasięgu   |
 * | Termistor            | NTC 100kΩ (Beta=3950)      | Pomiar temperatury    |
 * | Rezystor             | 100kΩ (0.25W)              | Dzielnik z termistorem|
 * | Czujnik Halla        | 3144                        | Pomiar obrotów (RPM)  |
 * | Rezystory dzielnika  | 2x 100kΩ (0.25W)           | Dzielnik napięcia 1:2 |
 * | Kondensator          | 1000µF/6.3V                | Stabilizacja 3.3V     |
 * 
 * ============================================================================
 * PODŁĄCZENIA (ESP32-S3 SuperMini)
 * ============================================================================
 * 
 * UWAGA: Unikamy pinów 19 i 20 (zajęte przez native USB ESP32-S3)
 * 
 * GPS (moduł HT1818Z3G5L):
 * ----------------------------------------------------------------------------
 * | GPIO ESP32 | Funkcja     | Podłączenie                               |
 * |------------|-------------|-------------------------------------------|
 * | 12         | RX (odbiór) | TX (nadajnik modułu GPS)                  |
 * | 13         | TX (nadajnik)| RX (odbiór modułu GPS)                   |
 * |            |             |                                           |
 * | Prędkość:  230400 baud (autodetekcja 4800-230400)                      |
 * | Częstotliwość: 10Hz (komendy PMTK220,100)                              |
 * | Komunikaty: tylko GGA i RMC (PMTK314)                                  |
 * | Zapis:     PMTK286,1 (zapis do pamięci modułu)                         |
 * 
 * Czujnik temperatury (NTC 100kΩ):
 * ----------------------------------------------------------------------------
 * | GPIO ESP32 | Funkcja              | Podłączenie                            |
 * |------------|----------------------|----------------------------------------|
 * | 11         | Analogowy (ADC1)     | Dzielnik napięcia:                     |
 * |            |                      | 3.3V ---[100kΩ]---[NTC]---GND         |
 * |            |                      |           |                            |
 * |            |                      |        GPIO11                          |
 * |            |                      |                                        |
 * | Uwaga: NTC 100kΩ (Beta=3950) do pomiaru temperatury silnika            |
 * |        Zakres pomiarowy: 0-260°C (typowo do 180°C)                     |
 * |        Filtr: średnia ruchoma z 10 próbek                              |
 * 
 * Czujnik obrotów (Hallotron 3144):
 * ----------------------------------------------------------------------------
 * | GPIO ESP32 | Funkcja              | Podłączenie                            |
 * |------------|----------------------|----------------------------------------|
 * | 10         | INPUT_PULLUP         | Sygnał z czujnika Halla                |
 * |            |                      | (zwiera do GND przy wykryciu magnesu)  |
 * |            |                      |                                        |
 * | Uwaga: Magnes zamontowany na wale silnika generuje 1 impuls/obrót      |
 * |        Przerwanie na zboczu opadającym (FALLING)                        |
 * |        Filtr: mediana z 5 próbek                                       |
 * 
 * Pomiar napięcia baterii (dzielnik napięcia):
 * ----------------------------------------------------------------------------
 * | GPIO ESP32 | Funkcja              | Podłączenie                            |
 * |------------|----------------------|----------------------------------------|
 * | 8          | Analogowy (ADC1)     | Dzielnik 1:2:                          |
 * |            |                      | Bateria(+) ---[100kΩ]---[100kΩ]---GND |
 * |            |                      |                    |                   |
 * |            |                      |                 GPIO8                  |
 * |            |                      |                                        |
 * | Uwaga: Zakres pomiarowy: 0-6.6V (dla LiPo 2S max 8.4V zmień dzielnik)  |
 * |        Wzór: V_batt = (V_adc / 4095) * 3.3 * 2.0                       |
 * 
 * Zasilanie:
 * ----------------------------------------------------------------------------
 * | Wersja           | Zasilanie              | Pobór prądu | Uwagi                |
 * |------------------|------------------------|-------------|-----------------------|
 * | Podstawowa (lekka)| Z odbiornika RC 5V     | ~200mA      | Brak pomiaru baterii  |
 * |                  |                        |             | i RPM (opcjonalnie)   |
 * |------------------|------------------------|-------------|-----------------------|
 * | Rozszerzona      | Bateria LiPo 2S 7.4V   | ~350mA      | Pełna funkcjonalność  |
 * | (pełna)          | + stabilizator 5V/1A   |             |                       |
 * |------------------|------------------------|-------------|-----------------------|
 * | Kondensator      | 1000µF/6.3V między     | -           | Stabilizacja napięcia |
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
